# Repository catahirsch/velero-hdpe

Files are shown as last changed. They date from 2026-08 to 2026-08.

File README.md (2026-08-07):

# HDPE open daysailer

A 6.48 m open daysailer in high-density polyethylene, developed from two base
models: the **RS Aira 22** (dimensional envelope, 6-seat cockpit, rig concept) and
the **Flow 19** (retractable pivot keel plus water ballast, no-winch
2:1 purchase).

Requirements come from `notes.txt`.

---

## Headline results

| | |
|---|---|
| LOA / beam / draft | 6.48 m / 2.35 m / 0.22 m keel up, 1.29 m down |
| Displacement | 750 kg light, 1730 kg full load (6 crew + 500 L) |
| Ballast | 213 kg lead (28.4%) + 500 L water in the bench tanks |
| Sail area | 22.0 m² upwind, SA/D 15.5 full load |
| Structure | rotomoulded HDPE double skin, 5 mm skins / 50 mm gap, 9.5 kg/m² |
| Envelope compliance | **0 violations** |
| Cockpit self-drains | yes, +56 mm with 6 crew and 500 L aboard |
| Self-righting from 180° | **no — AVS 112°** light, ~105° tanks full. See below. |

### Three findings worth knowing up front

**1. HDPE costs essentially nothing in weight.** A rotomoulded double skin at
346 kg is within 12 kg of the GRP shell implied by the Aira's published figures.
The 46 kg of ballast lost against the Aira is bought by the **electric
auxiliary** (+58 kg), not the plastic. But single-skin HDPE is *not* viable —
deflection governs, requiring 23 mm and 710 kg of shell.

**2. The requirement envelope is the RS Aira's spec sheet.** LOA 6.50, DIS 750,
SQM 22.0 (14+8) are that boat's numbers, near-verbatim. Useful to know, because
they already encode GRP structure and no electric drive.

**3. True self-righting is a beam problem, not a ballast or open-cockpit
problem.** Sealing the cockpit entirely moves AVS by ~1°. Adding 800 kg of lead
gets to 149°, not 180°. What works is narrowing: 1.80 m beam and ~450 kg of
ballast self-rights, at ~990 kg displacement — which breaks the 6-abreast
cockpit and the 750 kg cap. **This requires a decision.**

The water ballast (`BAL <500` = 500 L) lives **inside the bench seats** (client
decision): one 250 kg tank filled to windward is worth about two crew on the
rail, and empty benches are the cockpit's sealed reserve buoyancy. The height
trade is real: at bench height, filling both tanks *costs* ~6° of AVS (under-sole
tanks would have gained ~4° via the RNLI righting-tank mechanism). Operating
rule: with a full crew sail tanks-empty; short-handed, fill the windward tank.

## Documents

| | |
|---|---|
| [`docs/01-requirements.md`](docs/01-requirements.md) | Conflict-resolved requirements, provenance of every figure, open items |
| [`docs/02-design-spec.md`](docs/02-design-spec.md) | Full design: hull form, HDPE structure, systems, build method, certification |
| [`docs/03-self-righting.md`](docs/03-self-righting.md) | Trade study and four costed options for the self-righting conflict |
| [`docs/04-build-spec.md`](docs/04-build-spec.md) | **Builder's package**: dimensions + tolerances, materials with grades, scantlings, hard points, foil/rig dimensions, water-ballast system, build sequence |
| [`docs/05-regulatory.md`](docs/05-regulatory.md) | **Argentina (PNA) + Chile (DIRECTEMAR)** path: approvals, registration, equipment by zone, the water-ballast friction point — from the primary ordinances |
| [`docs/06-compliance-notes.md`](docs/06-compliance-notes.md) | Line-by-line compliance matrix against the client's notes.txt — 30/33 met, the 3 that need a decision |
| [`docs/09-diseno-estilo.md`](docs/09-diseno-estilo.md) | Diseño: paletas de color para HDPE, terminaciones, detalles de confort, anti-ideas |
| [`docs/07-cost-analysis.md`](docs/07-cost-analysis.md) | Cost of building in Chile: welded one-off ~USD 64k mid vs rotomoulded series; parameterized model in `calc/costs.py` |
| [`autoadrizante/specs.md`](autoadrizante/specs.md) | **Self-righting variant (chosen resolution, 2026-08-07)**: same open 2.35 m boat + sealed mast + 60 L masthead float, *modelled in the GZ curves* — recovers unaided to 156°, turtle energy 2516 → 302 J. Full parallel of `out/`: specs, [changes vs baseline](autoadrizante/cambios.md), report, audit (22 checks), costs, 3DM + previews, STL, offsets, 8-sheet planos, water renders, physics GIF, presentation PDF — plus an **expanded options study** (section 4 of `presentacion.pdf`; raw run in `opciones.txt`): 8 righting options vs notes.txt, incl. an inflatable masthead bag that reaches literal 180° on the 2.35 m hull |

## Client viewer

**Live:** https://catahirsch.github.io/velero-hdpe/

Everything — specs, options data, blueprints, PDFs, interactive 3D model,
design/colour studies, downloads — in one browser page. To run it locally
instead:

```bash
python3 -m http.server 8000     # from the project folder (or double-click visor.command)
# then open http://localhost:8000
```

`index.html` loads the options comparison live from `autoadrizante/opciones.json`,
renders `specs.md`/`cambios.md`, embeds `planos.pdf` and `presentacion.pdf`, and
shows the hull STL (variant with rig + masthead float, and the narrow Option D
reference) in an orbitable three.js viewer. Regenerating the model outputs
updates the page — nothing on it is hand-copied.

## Competition (concurso/)

A design competition for UTN naval-engineering students built on this project:
teams submit a 14-parameter JSON, `python3 -m concurso.evaluar` turns it into a
real boat on the same physics chain (GZ curves, weight budget, envelope) and
scores it; `concurso/leaderboard.py` builds the ranking shown at
[/concurso/](https://catahirsch.github.io/velero-hdpe/concurso/). Rules in
`concurso/bases.md`, challenges in `concurso/desafios.md`. The reference
variant scores 79.9/100 — that's the boat to beat.

## Running it

```bash
python3 -m calc.report            # full calculation chain  (~10 s)
python3 -m calc.trade             # self-righting sweeps    (~4 min)
python3 -m calc.options           # costed resolution options (~5 min)
python3 -m geom.hull --both       # STL meshes + tables of offsets
python3 -m geom.export_3dm --both # Rhino .3dm visualization models
python3 -m calc.costs             # Chilean build cost model -> out/costs.txt
python3 -m geom.animate_righting  # self-righting animation -> out/selfrighting.gif
python3 -m calc.presentation      # client-facing PDF -> out/presentacion.pdf
python3 -m calc.audit             # buildability audit (15 physical checks)
python3 -m geom.drawings          # construction drawings -> out/planos.pdf
python3 -m geom.render_ideas      # design study: colorways + styling
python3 -m geom.render_scene      # 'photos': boat on the water, lit + reflections
```

Requires numpy, scipy, matplotlib; `rhino3dm` additionally for the .3dm export.
Polygon clipping and the STL writer are implemented directly.

### Outputs, in `out/`

| File | Contents |
|---|---|
| `report.txt` | Geometry, scantlings, weights, hydrostatics, stability, compliance |
| `trade_study.txt` | Ballast / beam / cockpit / depth sweeps and the frontier |
| `options.txt` | The four resolution options with costs |
| `gz_curves.png` | GZ curves, 0–180°, intact and flooded, light and loaded |
| `hull_lines.png` | Body plan, profile, plan |
| `trade_frontier.png` | Self-righting frontier and AVS vs ballast ratio |
| `hull_baseline.stl` | Baseline hull mesh, metres |
| `hull_selfrighting.stl` | 1.80 m beam variant that meets the requirement (452 kg keel) |
| `offsets_*.txt` | Tables of offsets for lofting or a builder |
| `boat_baseline.3dm` | Rhino model: hull with cockpit, keel, rudders, rig, tanks, waterlines — layered |
| `boat_selfrighting.3dm` | Same for the 1.80 m beam variant |
| `preview_3dm.png`, `preview_cockpit.png` | Quick renders of the .3dm contents |
| `foto_patagonia_navegando.png`, `foto_aira_fondeado.png` | El bote **en el agua**: renders iluminados con flotación y escora reales, velas izadas (`geom/render_scene.py`) |
| `diseno_colores.png`, `diseno_perfil.png` | Estudio de diseño: 4 paletas de color + elementos de estilo (`geom/render_ideas.py`) |
| `planos.pdf` | **7 láminas de construcción acotadas** (GA, formas, sección maestra, quilla, espejo/timón, plano vélico, lastre de agua) |
| `audit.txt` | Auditoría de constructibilidad — 15 verificaciones físicas, todas PASS |
| `presentacion.pdf` | **Resumen completo en castellano, listo para presentar** (12 páginas) |
| `selfrighting.gif` | **Animación**: ambos botes soltados invertidos — el base queda tortuga, la variante 1.80 m vuelve sola (`geom/animate_righting.py`) |

## Code layout

```
calc/
  params.py       all design parameters, provenance-tagged  <- start here
  geometry.py     stations, polygon clipping, heeled hydrostatics
  scantlings.py   HDPE panel sizing, creep-derated
  weights.py      weight and VCG budget; ballast as the remainder
  stability.py    GZ curves 0-180 deg, intact and flooded; sail carrying
  trade.py        parameter sweeps for the self-righting study
  options.py      costed resolution options
  report.py       driver -- runs everything, writes report and plots
geom/
  hull.py         mesh generation, STL export, developability check
  export_3dm.py   Rhino .3dm export: full boat on layers, for visualization
  animate_righting.py  physics animation of the self-righting comparison
calc/
  presentation.py the client-facing PDF builder (Spanish)
  audit.py        buildability audit: 15 physical consistency checks
geom/
  drawings.py     dimensioned construction drawings (7 sheets, Spanish)
```

Every parameter lives in `calc/params.py`, tagged with its source:
`[AIRA]` published spec, `[FLOW]` from `notes.txt`, `[NOTES]` stated in the brief,
`[ASSUM]` an assumption, `[MAT]` a material property. Change an assumption there
and the whole chain follows.

## Method notes

- **Stability** is computed from real geometry, not coefficients: each station is
  rotated into the earth frame and clipped against the waterplane with
  Sutherland-Hodgman, then integrated. Clipping a simple polygon against one
  half-plane leaves degenerate edges lying exactly along the clip line, where
  they contribute nothing to the shoelace area — so areas and centroids are exact
  without a geometry library.
- **Two GZ curves** are produced for every case. *Intact* treats the cockpit as
  watertight and is valid only up to the downflooding angle (44°). *Flooded* lets
  the cockpit fill once its opening immerses, and is the physically meaningful
  curve beyond that. The difference between them is small, which is itself the
  key result in the trade study.
- **Displacement is not held constant** in the trade sweeps. Ballast is added on
  top of the fixed weight, so each figure shows the displacement it implies.
- **ISO 12215-5 has no rotomoulded-PE path.** Pressures follow its form so the
  numbers are recognisable, but they are indicative, not a compliance route. At
  6.50 m the boat falls under ISO 12217-2, not 12217-3 — 0.50 m the wrong side of
  a cliff edge in certification cost.

## Caveats

- Flow 19 figures are unverified — its source URL returns HTTP 403.
- The flooded-cockpit model **removes buoyancy but does not add trapped water as
  weight**. That is correct for a cockpit draining aft through an open transom at
  moderate heel, where the internal water level equals the sea. At large heel and
  inverted, some water would be trapped above sea level, and its weight would
  reduce GZ further. So the model is **optimistic about self-righting** — and the
  boat still fails the test. The conclusion in `docs/03` is robust in the
  direction that matters.
- Aerodynamic heeling uses a single effective coefficient (1.05); it is sizing-
  grade, not VPP-grade.
- Panel formulas assume clamped long plates. Real corners and openings need
  detailed checks.
- No structural FEA. The hard points in `docs/02` §6 are where that effort
  belongs.

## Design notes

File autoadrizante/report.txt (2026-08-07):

==============================================================================
VARIANTE AUTO-ADRIZANTE -- masthead buoyancy, modelled honestly
==============================================================================
  Concept: baseline 2.35 m open daysailer, unchanged, plus a sealed
  spar (30 L usable) and a 60 L / 2.5 kg crown float.
  Design condition for the claim: keel DOWN and LOCKED, tanks EMPTY.

==============================================================================
1. WEIGHT BUDGET  (float aloft, paid for by the keel remainder)
==============================================================================
item                                     kg    z (m)      kg.m   note
------------------------------------------------------------------------------------------------------
HDPE shell (hull+deck)                346.3    0.420     145.4   9.5 kg/m2 x 32.5 m2
keel case + pivot structure            22.0    0.350       7.7   welded PE bosses, bolted
rudder + tiller (single, kick-up)      15.0    0.550       8.2   centreline transom-hung; client amendment 2026-08-06
mast + boom + standing rig             32.0    3.100      99.2   short mast, no backstay
sails (main + jib + furler)            16.0    2.200      35.2   square-top, lazy bag
deck hardware + 2:1 systems            19.0    0.780      14.8   no winches
electric motor                         26.0    0.550      14.3   ~4 kW outboard format
battery                                31.6    0.220       6.9   3.0 kWh LiFePO4
spray hood + cockpit tent              11.0    0.950      10.4   stowed
anchor, lines, safety gear             18.0    0.400       7.2   
keel ballast (lead)                   210.6   -0.860    -181.1   REMAINDER of the 750 kg cap, minus the crown float
masthead crown float                    2.5    9.550      23.9   60 L PE ellipsoid + bracket
------------------------------------------------------------------------------------------------------
LIGHT (incl. ballast)                 750.0    0.256
LOADED (6 crew + water)              1730.0    0.555

  VCG light rises 31 mm for the float -- the GZ curves below already carry that penalty.

==============================================================================
2. GZ CURVES  (2.35 m beam; 'con aparejo' counts the sealed rig)
==============================================================================
  case                     GZmax     AVS  rec.limit  neg area  GZ>0 to 180
  light/flooded/bare       0.643   109.8      109.8    0.3420        False
  light/flooded/rig        1.029   155.8      155.8    0.0411        False
  light/intact/rig         1.031   154.8      154.8    0.0490        False
  loaded/flooded/rig       0.373    83.6      124.0    0.1471        False

==============================================================================
3. VERDICT  (governing case: light ship, cockpit flooded, tanks empty)
==============================================================================
  Bare hull (baseline):   AVS 110 deg, stable inverted,
                          0.342 m.rad = 2516 J holding it turtle.
  With sealed rig+float:  GZ stays positive past 110 deg --
                          the boat recovers unaided from any heel up to 155.8 deg.
                          Residual inverted pocket: 155.8-180 deg, 0.0411 m.rad = 302 J
                          (8x shallower than the baseline's).
  Energy barrier guarding that pocket (area 110-156 deg): 0.358 m.rad = 2633 J --
  to turtle, a seaway must push the boat through ALL of it; to release,
  it only has to nudge the boat 24.2 deg. In any water rough
  enough to capsize this boat, the pocket is not a resting state.

  Claim for the spec sheet / placard: AUTO-ADRIZANTE con quilla abajo y
  trabada y tanques vacios; el flotador de tope hace el 180 inalcanzable
  y el barco vuelve solo desde cualquier escora hasta 156 grados.

==============================================================================
4. FLOAT SIZING  (why 60 L: sweep at 31 stations, 5 deg)
==============================================================================
   float (L)  rec.limit  neg area  GZ>0 to 180
           0      123.4    0.2211        False
          20      137.6    0.1279        False
          40      148.1    0.0726        False
          60      155.9    0.0396        False
          80      162.0    0.0208        False
  Below ~40 L the float cannot carry the immersed rig's weight with
  margin (rig 32 kg + float, buoyancy needed > ~35 kg); 60 L gives a
  1.7x margin and costs 2.5 kg. Beyond 80 L the recovery limit barely
  moves -- the residual pocket is pinched against 180 by symmetry, not
  by float size.

==============================================================================
5. OTHER CONDITIONS
==============================================================================
  Loaded (6 crew + 500 L), flooded, with rig: recovery limit 124 deg.
  Keel UP: NOT self-righting in any variant -- keel-up is a launch/
  recovery state only. The keel lock (L4) is what makes the claim hold
  through a knockdown: an unlocked keel falling into the case at 120 deg
  would remove most of the righting moment when it is needed most.
  Downflooding angle at full load: 37 deg (unchanged from base).

Report written to /Users/catalinahirsch/Desktop/bote/autoadrizante/report.txt

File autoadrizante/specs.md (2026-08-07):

# Especificacion — variante auto-adrizante

Velero abierto HDPE 6.48 m, identico al baseline en casco, cockpit, quilla,
aparejo y sistemas, mas el **paquete de flotabilidad de tope de mastil**. La
decision que encierra esta variante: mantener el daysailer abierto y liviano,
y comprar los grados de adrizado que faltan con **volumen sellado en altura**,
no con plomo.

## Dimensiones y pesos

| | |
|---|---|
| LOA / LWL | 6.48 m / 6.30 m |
| Manga | 2.35 m (se mantiene el cockpit de 6 plazas) |
| Calado | 0.30 m quilla arriba — 1.29 m abajo |
| Desplazamiento rosca | 750 kg (tope 750) |
| Quilla (plomo) | 211 kg (28.1 %) |
| Lastre de agua | 2 × 244 L en bancos-tanque — **vacios para la condicion de diseno** |
| Superficie velica | 22.0 m² (mayor 14 + foque 8) |
| Estructura | HDPE doble piel 2×5 mm / 50 mm, 9.5 kg/m² |

## El paquete auto-adrizante (lo unico que cambia)

| Elemento | Especificacion |
|---|---|
| Flotador de tope | 60 L, elipsoide PE rotomoldeado 1.00 × 0.34 m, carenado proa-popa, 2.5 kg con soporte |
| Mastil sellado | 30 L utiles: espuma de cierre en pie, tope y cajeras; drizas externas o en conducto |
| Traba de quilla | obligatoria en posicion BAJA (ya en L4): una orzada no debe retraerla |
| Costo en plomo | el flotador se paga con 2.5 kg de quilla (213 → 211 kg) |

## Resultado de estabilidad (condicion gobernante: rosca, cockpit inundado, tanques vacios)

| | Sin flotador (base) | Con mastil sellado + flotador |
|---|---|---|
| AVS | 110° | GZ sigue positivo mas alla de 110° |
| Limite de recuperacion sin ayuda | 110° | **155.8°** |
| Energia que sostiene la tortuga | 2516 J | 302 J |
| Equilibrio invertido estable | si — el barco queda tortuga | reducido a un bolsillo de 24.2° junto a 180° |

**La afirmacion honesta**: con quilla abajo y trabada y tanques vacios, el
barco vuelve solo desde cualquier escora hasta 156°. El bolsillo
invertido residual (24.2° de ancho, 302 J) no es un
estado de reposo en ninguna mar capaz de dar vuelta el barco: para entrar hay
que atravesar toda la barrera positiva de la curva; para salir alcanza con
24° de perturbacion. A efectos operativos: **anti-tortuga +
retorno autonomo**, y las cinchas de piso quedan como respaldo (y para la
condicion quilla-arriba en playa).

## Condicion de diseno — placa junto a la quilla (grabar)

> AUTO-ADRIZANTE SOLO CON: QUILLA ABAJA Y TRABADA · TANQUES VACIOS
> QUILLA ARRIBA = SOLO BOTADURA / PLAYA · LLENAR TANQUES = VER PLACA DE LASTRE

El lastre de agua queda como sistema de rendimiento (tanque de barlovento con
poca tripulacion), nunca como dependencia de seguridad: la curva verde se
calcula con tanques vacios.

## Lo que esta variante NO cambia

Cockpit 3.20 × 1.72 m de 6 plazas, piso autoachicable (+56 mm a plena carga),
espejo semiabierto, bancos-tanque sellados, cuddy con doble tambucho, aparejo
sin winches 2:1, timon unico abatible, motor electrico con bateria bajo el
piso, remolque sin permiso especial. Desplazamiento rosca sigue en
750 kg.

## Archivos de esta carpeta

| Archivo | Contenido |
|---|---|
| `specs.md` / `cambios.md` | esta especificacion + registro de cambios vs baseline |
| `report.txt` | corrida completa del modelo (pesos, curvas, dimensionado del flotador) |
| `audit.txt` / `costs.txt` | auditoria 22 verificaciones (15 base + 7 del flotador); costos con delta |
| `gz_curves.png` / `hull_lines.png` | curvas GZ con y sin paquete de tope; plano de lineas |
| `boat_autoadrizante.3dm` | modelo Rhino por capas, con flotador de tope |
| `preview_3dm.png` / `preview_cockpit.png` | vistas rapidas del 3DM |
| `hull_autoadrizante.stl` | malla del casco (identica al baseline, m) |
| `offsets_autoadrizante.txt` | tabla de puntos para loftear |
| `planos.pdf` | 8 laminas: las 7 constructivas + L8 flotador y condicion de diseno |
| `selfrighting.gif` + `anim_*.png` | animacion fisica: soltados a 150°, con y sin paquete de tope |
| `foto_*.png` / `diseno_*.png` | el bote en el agua y estudio de color, flotador a la vista |
| `opciones.txt` / `.json` / `opciones_gz.png` / `opciones_board.png` | exploracion ampliada: 8 opciones de auto-adrizado contra notes.txt (insumos de la seccion 4 de la presentacion) |
| `presentacion.pdf` | resumen para el cliente en castellano, con la comparacion de opciones y recomendacion integradas |

Generado por `python3 -m calc.autoadrizante`, `geom.autoadrizante`,
`geom.render_autoadrizante`, `geom.animate_autoadrizante`,
`calc.audit_autoadrizante` y `calc.presentacion_autoadrizante`. Mismas
advertencias que el modelo base: el caso inundado no agrega el peso del agua
atrapada (optimista; cuantificado en docs/03), y el proyecto requiere firma
de ingeniero naval.

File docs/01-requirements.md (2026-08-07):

# Requirements — HDPE open daysailer

Derived from `notes.txt`, with every figure traced to a source. Nothing in this
document is invented; where a number had to be assumed it says so.

---

## 1. Where the envelope came from

The six dimensional limits in `notes.txt` are, to within rounding, the published
spec sheet of the **RS Aira 22**. That is worth stating plainly, because it means
the envelope is not an independent set of targets — it is one existing GRP boat's
achieved numbers, and it already encodes GRP's structural efficiency and the
absence of an electric drive.

| Note | Stated limit | RS Aira 22 (published) | Reading |
|---|---|---|---|
| `LOA <6.50` | 6.50 m | **6.50 m** | identical |
| `BEA <2.50` | 2.50 m | 2.20 m | rounded up to the EU road limit |
| `DIS <750` | 750 kg | **750 kg** | identical |
| `SQM <22` | 22 m² | **22.0 m²** (14.0 main + 8.0 jib) | identical |
| `BAL <500` | 500 **litres** of water ballast | — (Aira carries none) | see §2 |
| `CBD <1.30` | 1.30 m | 1.20 m | keel lowered |

Source: rssailing.com/project/rs-aira/, fetched 2026-08-06.

**Note on naming:** `notes.txt` line 17 reads *Aira 22* (RS Aira). The original
request said "Aria 22". The RS Aira is the boat.

The **Flow 19** figures on lines 26–33 could not be verified — the
carbonmade.com URL returns HTTP 403. They are used as recorded by the designer:
beam 2.30 m, draft 1.30 m, displacement 450 kg, 70 kg swing keel, 2 × 60 kg water
ballast, twin pivoting rudders, 2:1 purchase, no traveller, no backstay.

## 2. Resolved parameters

`CBD` (line 8) and `CND` (line 27) are the same parameter under two spellings.
Read as **keel depth, lowered** — not overall draft, which for a pivot-keel boat
is a different and much smaller number (canoe-body draft, computed at 0.22 m
light / 0.29 m loaded).

`DIS <750` is confirmed as **light/dry displacement including ballast**. Six crew
and the water ballast sit on top of it, so full-load displacement is ~1730 kg.
This is the definition the whole weight budget is built on.

`BAL <500` is confirmed (designer, 2026-08-06) as **500 litres of water
ballast** — not a cap on lead. The design carries 2 × 250 kg tanks (488 L of
seawater, inside the cap) built into the cockpit benches and double sole, so the
tanks are the sealed reserve buoyancy when empty and the ballast when full. The
keel ballast is a separate quantity, solved as the remainder of the 750 kg
budget (213 kg).

## 3. Intended use — settled

An open daysailer, not a cruiser:

- 6-seat cockpit, no cabin; bow cuddy with a fabric shelf (`estante tela`)
- Self-draining cockpit, draining aft through a semi-open transom
- Spray hood plus cockpit tent for shelter; flat foredeck for sunbathing
- Electric auxiliary
- Single centreline kick-up rudder with short tiller (client amendment 2026-08-06; notes line 39 said two)
- Pivoting keel
- Furling jib, centred high boom, short mast, square-top main
- No traveller, no backstay, no winches — 2:1 purchase throughout
- Double bow hatch (`doble tambucho proa`); removable righting straps on the
  sole; 1″×1″ foot-bracing battens

## 4. What each base model contributes

**RS Aira 22** — the dimensional envelope, the 6-adult cockpit, the general
rig concept (high centred boom, short mast, square-top main, furling headsail),
and the reference point for what 750 kg buys in a 6.5 m hull.

**Flow 19** — the ballast strategy (light pivoting keel plus symmetric water
ballast), the no-winch 2:1 purchase system (its twin rudders were later dropped by client amendment), and the
no-traveller/no-backstay rig simplification.

## 5. Requirements that conflict

### 5.1 True self-righting vs. everything else — **unresolved, decision needed**

The stated requirement (confirmed after the conflict was flagged) is recovery
from 180° unaided. The calculations say this is **not achievable within the rest
of the brief**, and the reason is not the one usually assumed.

- The baseline reaches AVS **112°** with 213 kg of ballast (28% ratio) and has a
  **stable inverted equilibrium**.
- Ballast alone does not fix it. Even at 1000 kg of lead — displacement ~1540 kg
  on a 6.5 m hull — AVS only reaches 149°.
- **Sealing the cockpit barely helps** (AVS 112.4° sealed vs 112.2° flooded).
  When inverted the boat floats so high that the cockpit is mostly out of the
  water anyway. The "open boat loses its reserve buoyancy" argument is wrong here.
- The binding constraint is **beam-to-depth ratio**. 2.35 m of beam on 0.755 m of
  depth is a hull that is stable upside down, and that is the same form stability
  that makes it stiff upright and lets it carry 6 people and 22 m².

Cheapest configuration that genuinely self-rights: **1.75–1.80 m beam, 417–452 kg
ballast, ~954–988 kg displacement** — which breaks the 6-abreast cockpit and
exceeds `DIS 750` by 27–32%.

Full trade study and four costed options: [`03-self-righting.md`](03-self-righting.md).

### 5.2 Lead is scarce; water is not

The 750 kg budget leaves **213 kg** for the keel after structure, rig, foils,
hardware and the electric drive — 46 kg less than the Aira, bought by the
electric auxiliary. The 500 L of water ballast rides on top of the light-ship
budget and lives **inside the bench seats** (client decision): filled to
windward it is worth about two crew on the rail; empty, the benches are the
cockpit's reserve buoyancy. Filling both tanks symmetrically costs ~6° of AVS
at bench height and is only worth doing for motion damping in a seaway with a
small crew.

### 5.3 ISO certification vs. the material — cost and schedule risk

**ISO 12215-5 has no rotomoulded-PE path.** Its scantling formulas cover FRP,
aluminium, steel, plywood and wood. Certification of a PE hull runs through
physical testing instead.

At 6.50 m hull length the boat falls under **ISO 12217-2** (sailing boats,
hull length ≥ 6 m) — *not* 12217-3, which covers boats under 6 m. This is a
cliff edge, not a gradient: dropping hull length below 6.00 m would move the boat
into a materially simpler and cheaper stability-assessment path. At 6.50 m LOA
the boat sits just the wrong side of it, by 0.50 m.

## 6. Questions the notes left open

| # | Question | Status |
|---|---|---|
| 1 | Freeboard and cockpit sole height (line 30) | **Resolved by calculation.** Sole at 0.385 m above baseline drains with +168 mm margin light, **+56 mm** with 6 crew and 500 L of water ballast aboard (1730 kg). Tight but positive; raising the sole 30 mm would buy comfort at the cost of cockpit depth. |
| 2 | How to fill water ballast under way (line 57) | **Open.** Scoop/venturi intake vs. powered pump changes electrical load and thru-hull count. Emptying by air pump is already specified (line 56). |
| 3 | True self-righting | **Open — needs a decision.** See §5.1. |
| 4 | Flow 19 source data | **Blocked.** URL returns 403. |

## 7. Assumptions this model makes

All are tagged `[ASSUM]` in `calc/params.py` and can be changed in one place:

- Beam 2.35 m (between the Aira's 2.20 and the 2.50 road cap, for form stability)
- LOA 6.48 m, LWL 6.30 m
- Canoe-body depth 0.755 m; cockpit 3.20 m × 1.72 m; sole at 0.385 m
- Keel ballast VCG 0.86 m below baseline, lowered
- Water ballast tanks: 2 × 250 kg, centroid 0.26 m above baseline, 0.72 m off
  centreline, built into the benches and double sole
- Electric drive: ~4 kW outboard-format motor (26 kg) + 3.0 kWh LiFePO₄ (32 kg)
- Crew 80 kg each (ISO uses 75 kg; 80 is more honest)
- Design category C (inshore)
- HDPE: ρ 950 kg/m³, short-term flexural modulus 1100 MPa, **creep-derated
  design modulus 250 MPa**, allowable bending stress 7 MPa

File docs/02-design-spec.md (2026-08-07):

# Design specification — HDPE open daysailer

6.48 m open daysailer in high-density polyethylene, based on the RS Aira 22
(envelope, cockpit, rig concept) and the Flow 19 (ballast strategy,
purchase system).

All figures from `calc/report.py`; raw output in `out/report.txt`.

---

## 1. Principal dimensions

| | Baseline | Limit | RS Aira 22 |
|---|---|---|---|
| LOA | 6.48 m | 6.50 | 6.50 m |
| LWL | 6.30 m | — | 6.45 m |
| Beam (sheer) | 2.35 m | 2.50 | 2.20 m |
| Beam (chine) | 1.88 m | — | — |
| Canoe-body depth | 0.755 m | — | — |
| Draft, keel up | 0.22 m light / 0.29 m loaded | — | — |
| Draft, keel down | 1.29 m | 1.30 | 1.20 m |
| Displacement, light | 750 kg | 750 | 750 kg |
| Displacement, full load (6 crew + 500 L) | 1730 kg | — | — |
| Keel ballast | 213 kg (28.4%) | — | 250 kg (33.3%) |
| Water ballast | 2 × 250 kg (488 L) | 500 L | none |
| Sail area, upwind | 22.0 m² | 22.0 | 22.0 m² |
| SA/D (full load) | 15.5 | — | — |
| VCG, light | 0.239 m above baseline | — | — |
| Design category | C (inshore) | — | — |

Baseline z = 0 is the lowest point of the canoe body. x = 0 at the transom.

## 2. Hull form

**Hard chine, two panels per side.** This is not stylistic. Both viable HDPE
processes want it: rotomoulding needs a shape that releases from a shell tool
without undercuts, and welded-sheet construction needs panels that develop flat.
A hard chine also gives more form stability than a round bilge of the same beam,
which matters when the ballast ratio is only 27%.

Plan form carries beam well aft to support the 6-seat cockpit and the semi-open
transom, with a fine entry forward to stop it pounding. Moderate rocker, flat run
aft.

### Developability

From `geom/hull.py`, using the standard test `det[t₁, t₂, (P₂−P₁)] = 0`:

| Panel | Mean twist | Peak | Location of peak |
|---|---|---|---|
| Bottom | 0.039 | 0.199 | x = 5.94 m |
| Side | 0.018 | 0.161 | x = 5.94 m |

**Sheet-formable from the transom to x = 4.10 m — 63% of LOA.** Forward of that
the entry twists too hard for flat PE sheet. Three ways out:

1. Rotomould the stem as a separate piece and butt-weld it on
2. Split the forward panels into narrower strakes
3. Straighten the entry (costs seakeeping)

If the whole hull is rotomoulded in one shot this is moot — a shell tool does not
care about developability.

## 3. Structure — the part that decides whether HDPE works

### Material design values

| Property | Value | Note |
|---|---|---|
| Density | 950 kg/m³ | rotomoulding grade |
| Flexural modulus, short-term | 1100 MPa | **not a design value** |
| Flexural modulus, creep-derated | **250 MPa** | 10 yr, 20 °C — use this |
| Allowable bending stress | 7.0 MPa | long-term |
| Weldable | yes | |
| Adhesively bondable | **no** | non-polar surface; weld or bolt |
| Thermal expansion | ~200 × 10⁻⁶ /K | ~10× steel — detail for it |

Designing to the short-term modulus is the single most common way plastic boat
structures end up floppy. Everything below uses 250 MPa.

### Deflection governs, not stress

For HDPE at this size the stiffness requirement is always the binding one:

| Panel | Pressure | Span | t for strength | t for stiffness | Governs |
|---|---|---|---|---|---|
| Bottom | 27.1 kPa | 0.40 m | 17.6 mm | **23.0 mm** | deflection |
| Side | 21.4 kPa | 0.40 m | 15.6 mm | **21.2 mm** | deflection |
| Deck | 7.5 kPa | 0.46 m | 10.6 mm | **17.2 mm** | deflection |
| Cockpit sole | 7.5 kPa | 0.36 m | 8.3 mm | **13.5 mm** | deflection |

Pressures follow the *form* of ISO 12215-5 (category C, m_LDC 1230 kg) so they are
recognisable, but see §6 — that standard does not actually cover PE.

**Single skin is not viable.** 23 mm of solid HDPE over 32.6 m² of shell is
**710 kg** — the whole displacement budget, before rig, keel or crew. The
HDPE/GRP thickness ratio for equal panel stiffness is 2.96×.

### Double skin is the answer

Two skins separated by a gap act as the flanges of an I-beam. Equivalent solid
thickness is `(6·t·d²)^(1/3)`, typically 4–5× the material actually used.

**Specification: 5.0 mm skins, 50 mm gap, kiss-offs at 75 mm pitch.**

| Panel | t equivalent | Required | Face stress | Skin needed locally | Verdict |
|---|---|---|---|---|---|
| Bottom | 42.2 mm | 23.0 mm | 1.44 MPa | 4.3 mm | **pass** |
| Side | 42.2 mm | 21.2 mm | 1.14 MPa | 4.0 mm | **pass** |
| Deck | 42.2 mm | 17.2 mm | 0.53 MPa | 2.8 mm | **pass** |
| Cockpit sole | 42.2 mm | 13.5 mm | 0.32 MPa | 2.8 mm | **pass** |

Areal mass **9.5 kg/m²** — 44% of the single-skin mass. Face stresses are an
order of magnitude below allowable; the kiss-off pitch is what sizes the skins,
not the global bending.

Shell mass: 32.6 m² × 9.5 kg/m² × 1.12 (reinforcement) = **346 kg**.

### The material is weight-neutral — the electric drive is not

Backing the Aira's shell mass out of its published figures (750 kg total, 250 kg
ballast, minus the same non-shell items this design carries, minus the electric
drive it does not have) gives an implied GRP shell of **358 kg**.

| | kg |
|---|---|
| RS Aira shell, implied (GRP) | 358 |
| This shell, HDPE double-skin | 346 |
| **Material penalty** | **−12** |
| Electric motor + battery | **+58** |
| **Ballast: Aira 250 → this boat 213** | **−37** |

**HDPE costs essentially nothing in weight.** A rotomoulded double skin is as
efficient as a stiffened glass laminate. The 46 kg of ballast lost against the
Aira is bought by the electric auxiliary, not the plastic.

If ballast ratio matters more than motoring range, a 1.5 kWh pack instead of
3.0 kWh returns ~16 kg to the keel.

## 4. Weight budget

Ballast is not an input — it is the remainder under the 750 kg cap.

| Item | kg | z (m) | Note |
|---|---|---|---|
| HDPE shell (hull + deck) | 346.3 | 0.420 | 9.5 kg/m² × 32.5 m² |
| Keel case + pivot structure | 22.0 | 0.350 | welded PE bosses, bolted |
| Rudder + tiller (single, kick-up) | 15.0 | 0.550 | client amendment 2026-08-06 |
| Mast + boom + standing rig | 32.0 | 3.100 | short mast, no backstay |
| Sails (main + jib + furler) | 16.0 | 2.200 | square-top, lazy bag |
| Deck hardware + 2:1 systems | 19.0 | 0.780 | no winches |
| Electric motor | 26.0 | 0.550 | ~4 kW outboard format |
| Battery | 31.6 | 0.220 | 3.0 kWh LiFePO₄ |
| Spray hood + cockpit tent | 11.0 | 0.950 | stowed |
| Anchor, lines, safety gear | 18.0 | 0.400 | |
| **Keel ballast (lead)** | **213.1** | **−0.860** | **remainder** |
| **Light, incl. ballast** | **750.0** | **0.239** | |
| **Full load (6 crew + 500 kg water)** | **1730.0** | **0.402** | |

## 5. Systems and layout

### Cockpit and freeboard — the open question, resolved

Cockpit 3.20 m × 1.72 m, sole at 0.385 m above baseline.

| Condition | Waterline | Sole freeboard | Drains? |
|---|---|---|---|
| Light ship | 0.217 m | **+168 mm** | yes |
| 6 crew + 500 kg water ballast (1730 kg) | 0.329 m | **+56 mm** | yes |

The self-draining cockpit works, draining aft through the semi-open transom, with
56 mm of margin in the worst case — tight but positive. If more margin is wanted,
each 10 mm of sole height buys 10 mm of margin at the cost of cockpit depth;
alternatively sail with one tank when fully crewed. Sheer freeboard 0.538 m light.

This closes `notes.txt` line 30.

### Ballast

- **Retractable pivoting keel, 213 kg total (163 lead + 50 fin)**, 1.29 m draft lowered, 0.30 m raised, pivot at
  x = 3.30 m. Ballast VCG 0.86 m below baseline when down.
- **Water ballast, 2 × 250 kg (488 L total, inside the 500 L cap)**, tanks built
  **into the cockpit bench seats**: sealed HDPE boxes, sole (0.385) to seat top
  (0.80), inboard face at y = 0.44, outboard face at the cockpit wall
  (y = 0.86). Water centroid when full: z ≈ 0.48, y ≈ ±0.65.

The bench-tanks do triple duty, and the three roles should be kept distinct:

1. **Empty and sealed** — they *are* the reserve buoyancy of the benches
   (`reserva flotabilidad`, line 38) and the seats. No separate foam or tankage.
2. **One tank filled to windward** — 250 kg at 0.65 m of lever ≈ 1.6 kN·m,
   about **two crew on the rail**. This is the payoff that earns the plumbing:
   sailing stiffness when short-handed. Heel at 16 kt drops from 10° to 5°.
3. **Both tanks filled** — adds 500 kg for damping and inertia only. At bench
   height this **costs ~6° of AVS** (111° → 105° light ship), unlike under-sole
   tanks which would gain ~4°. That is the price of seats-as-tanks; it was a
   deliberate trade for build simplicity, seating and reserve buoyancy.

**Operating rule that falls out of the numbers:** water ballast substitutes for
crew weight, it does not stack with it. With 5–6 crew aboard, sail tanks-empty
(the crew *is* the ballast; full tanks put the loaded AVS at ~85°). With 1–3
crew, fill the windward tank. Symmetric fill is for motoring or running in a
seaway, short-handed.

Only the keel does real work at large heel in every condition.

**Filling under way remains open** (`notes.txt` line 57). Scoop/venturi intake is
passive and free but only works above ~3 kt and adds two thru-hulls; a powered
pump adds ~180 W and a load on the same battery as the motor. Recommend the
scoop, with the air pump already specified for emptying (line 56).

### Rig

Centred high boom (1.80 m above baseline — audited to clear seated heads), short mast (8.60 m), square-top main 14.0 m²,
furling jib 8.0 m², no traveller, no backstay, no winches, 2:1 purchase.

Sail-carrying, 6 crew aboard:

| True wind | Tanks symmetric | Windward tank only |
|---|---|---|
| 8 kt | 2° | 0° |
| 12 kt | 5° | 1° |
| 16 kt | 10° | 5° |
| 20 kt | 17° | 12° |
| 25 kt | 28° | 25° |

Peak righting moment at **28 kt steady** — gusts reach it sooner, so first reef
goes in around 18 kt. SA/D 15.5 at full load (18.3 without the water ballast) is
moderate; the boat is stiff for its sail area.

Downflooding angle is **37°** at full load. For an open boat that is the number
to design the crew drill around.

### Foils and steering

Single centreline kick-up rudder with a short tiller (client amendment
2026-08-06 — the notes and Flow 19 had two). Kick-up keeps beaching and trailer
recovery. The lone blade is drawn deeper (0.85 m immersed) than each of the
former twins so it keeps grip at the 20–30° heel this boat sails at; expect
some rudder emergence in the worst gusts — ease the main first.

### Propulsion

~4 kW outboard-format electric, 3.0 kWh LiFePO₄ mounted low (z = 0.22 m) under
the sole. At 4 kt cruise the pack gives roughly 1.5–2 h of motoring.

## 6. Build method and certification

### Which process

| | Rotomoulding | Welded sheet |
|---|---|---|
| Tooling | High — shell tool for a 6.5 m hull | Low |
| Double skin | Natural, with kiss-offs | Must be fabricated |
| Developability | Irrelevant | Only 63% of LOA works as-drawn |
| Unit cost at volume | Low | Flat |
| Viable at 1–5 boats | No | Yes |

**Rotomoulding for production, welded sheet for a prototype.** The scantlings
above assume the rotomoulded double skin; a welded prototype needs an equivalent
stiffened structure — 12 mm sheet on 200 mm-pitch welded top-hat stiffeners gets
close at a weight penalty of roughly 40 kg.

### Hard points — the main structural risk

HDPE **cannot be adhesively bonded**. Every load path is welded or mechanically
fastened, and PE creeps under sustained load, so bolts pull through over time
unless the load is spread.

The rig makes this worse than usual: no traveller and a centred boom put the
entire mainsheet load into one centreline point, and with no backstay the
forestay is reacted by shroud geometry alone.

| Hard point | Detail |
|---|---|
| Mast step | Welded PE box, through-bolted to an aluminium spine spanning ≥3 station frames. Do not rely on the shell. |
| Chainplates | Full-depth aluminium backing plates through both skins, load spread over ≥0.15 m². |
| Mainsheet anchor | Centreline welded PE boss, through-bolted to a transverse alloy beam bearing on the keel case. |
| Keel pivot | Machined alloy trunnion in a welded PE case, bolted to a full-height bulkhead. Highest cyclic load on the boat. |
| Rudder gudgeons | Bolted through alloy backing plates, not tapped into PE. |
| Thermal | ~200 × 10⁻⁶ /K expansion: every alloy-to-PE joint needs slotted holes or compliant bushes, or it will yield through a season. |

### Certification path

**ISO 12215-5 has no rotomoulded-PE path** — it covers FRP, aluminium, steel,
plywood and wood. The scantling numbers in §3 are indicative, not a compliance
route. CE certification of a PE hull runs through **physical testing**:
instrumented panel tests to demonstrate equivalence, plus ISO 12217-2 stability
trials.

At 6.50 m hull length the boat falls under **ISO 12217-2** (sailing boats,
hull length ≥ 6 m). Below 6.00 m it would fall under 12217-3, which is a
materially cheaper and simpler path. **The boat is 0.50 m the wrong side of that
line.** If certification cost is a driver, shortening to under 6.00 m hull length
is the single highest-leverage change available — and it is worth pricing before
committing to 6.48 m.

Treat certification as a cost and schedule item with real risk attached, not a
checkbox. Budget for a test programme.

## 7. Open items

1. **Self-righting** — requirement conflicts with the brief. Decision needed.
   See [`03-self-righting.md`](03-self-righting.md).
2. **Water ballast filling under way** — scoop vs pump. Recommend scoop.
3. **Flow 19 source data** — unverified, URL returns 403.
4. **Certification strategy** — test programme scope and cost; whether to drop
   below 6.00 m hull length.

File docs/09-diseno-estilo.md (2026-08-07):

# Diseño y estilo — colores, terminaciones y detalles

Renders en `out/diseno_colores.png` (4 paletas), `out/diseno_perfil.png`
(elementos de estilo numerados) y **escenas en el agua** en
`out/foto_patagonia_navegando.png` / `out/foto_aira_fondeado.png` — el modelo
real flotando en su línea de flotación de cálculo, con velas y escora
(`python3 -m geom.render_scene`). Regenerables con `python3 -m geom.render_ideas`.

La restricción que ordena todo: **en HDPE el color va en la resina** (masterbatch
al momento de moldear). No hay pintura ni gelcoat — nada adhiere al PE — así que
el esquema de color es una decisión *previa al molde*, y a cambio el color es
pasante: los rayones y el uso no se notan como en gelcoat.

---

## 1. Las tres reglas técnicas del color en PE

1. **Cubierta, bancos y piso siempre claros.** El PE oscuro al sol toma 20–30 °C
   más que el claro; en un material que fluye con la temperatura eso significa
   más dilatación, más creep en herrajes, y quemarse al sentarse. Los costados
   pueden ser oscuros (verticales, menos insolación).
2. **El negro/carbono es el PE más longevo al UV** — por eso los kayaks de
   expedición son oscuros. Un casco grafito con cubierta clara es la combinación
   más durable.
3. **Blanco/claro es el más estable dimensionalmente** — si la prioridad es
   minimizar movimiento térmico (tolerancias de herrajes), la base clara gana.

## 2. Cuatro paletas propuestas (render en `diseno_colores.png`)

| Paleta | Costados | Franja | Cubierta | Bancos | Carácter |
|---|---|---|---|---|---|
| **PATAGONIA** | grafito | naranja | gris claro | naranja | máxima vida UV, no muestra el uso, acentos de alta visibilidad SAR |
| **CHILOÉ** | petróleo | crema | crema | pads "teca" | clásico de canal, esconde algas en la franja |
| **AIRA** | blanco roto | azul | gris perla | azul | el más fresco al sol, look astillero |
| **ARENA** | arena | oliva | crema | oliva | discreto en fondeaderos australes |

Recomendación: **PATAGONIA** para uso intensivo/alquiler (durabilidad + no
muestra uso), **AIRA** para clima cálido o si mandan las tolerancias.

## 3. Elementos de estilo (perfil numerado en `diseno_perfil.png`)

1. **Defensa perimetral de PE soldada** en la borda — perfil D extruido, soldado
   sobre el cordón casco-cubierta: lo protege, remata la línea y es el "trim"
   natural del material.
2. **Nombre en bajorrelieve ruteado + inlay de soldadura** en color de contraste
   — el rótulo que no se despega nunca. (El vinilo sobre PE requiere flameado y
   dura poco; evitarlo.)
3. **Franja de flotación en color de acento** — esconde la zona que se ensucia
   y estiliza el perfil bajo.
4. **Matrícula grabada** en amuras + nombre en aletas + puerto en espejo — la
   exigencia CL/AR (A-41/014 II.E) resuelta con el mismo grabado del punto 2.
5. **Apéndices en gris oscuro** (quilla, timón galvanizado pintado no — el acero
   va galvanizado y puede llevar recubrimiento epoxi sobre el galvanizado).
6. **Antideslizante moldeado** — textura guijarro/diamante EN el molde para
   cubierta, tapas de banco y piso. Sin pinturas antideslizantes (no adhieren).

## 4. Confort y detalles de cockpit

- **Pads EVA tipo teca en las tapas de banco** (el look madera de la paleta
  CHILOÉ): se fijan con pernos de PE soldados por debajo o botones a presión
  pasantes — nunca adhesivo. Aíslan térmicamente el asiento (resuelve el PE
  caliente/frío) y son el "cushion" que no se vuela.
- **Respaldo bajo continuo**: la brazola de la cubierta lateral, redondeada en
  el molde a r ≥ 40 mm.
- **Estiba**: el volumen de banco sobre el nivel de llenado (0.57→0.80 m) queda
  utilizable como estiba seca por las tapas registro — bolsos estancos.
- **Cuddy**: estante de tela (notes línea 20) + bolsillos de red en las paredes;
  los dos tambuchos dan luz y ventilación.
- **Bañera nocturna**: la carpa sobre la botavara a 1.80 m da altura de asiento
  en todo el cockpit — 3.2 m de "camarote" de lona.
- **Piso**: listón 1"×1" soldado (notes línea 47) en el eje + textura moldeada.

## 5. Lo que NO hacer en PE (anti-ideas)

- Pintar o gelcoatear cualquier superficie — se despega, siempre.
- Vinilos grandes — flameado + vida corta; solo aceptable para numerales de
  regata temporales.
- Herrajes "decorativos" atornillados al PE sin placa — fluencia y pérdida.
- Teca real atornillada — dilatación diferencial 10× la arranca; EVA o PE
  texturado.
- Colores oscuros en superficies horizontales — regla 1.

## 6. Cómo se pide esto en producción

Rotomoldeo: el masterbatch define **un** color por pieza moldeada. El esquema
multicolor se logra por: (a) casco y cubierta moldeados por separado en colores
distintos (ya son dos piezas), (b) franja y defensa como perfiles PE soldados en
color de acento, (c) tapas de banco moldeadas aparte (color 3), (d) inlays de
soldadura para gráfica. En chapa (prototipo): cada plancha PE500 viene de color
de fábrica — el esquema se arma por despiece, con la misma lógica.

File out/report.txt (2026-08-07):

==============================================================================
1. HULL GEOMETRY
==============================================================================
  LOA                     6.480 m
  LWL                     6.300 m
  Max beam (sheer)        2.350 m
  Beam at chine           1.880 m
  Depth of canoe body     0.755 m
  Hull shell area         17.41 m2
  Deck + cockpit area     15.14 m2
  Total shell area        32.55 m2
  Cockpit                 3.20 m long x 1.72 m wide, sole at z=0.385 m

==============================================================================
2. HDPE SCANTLINGS
==============================================================================
  Design category C, m_LDC assumed 1230 kg
  Material: HDPE (rotomoulding grade)
    short-term flex modulus  1100 MPa
    creep-derated modulus    250 MPa  <- design value
    allowable bending stress 7.0 MPa

  panel             p (kPa)   span   t_str  t_defl     governs
  bottom               27.1   0.40    17.6    23.0  deflection
  side                 21.4   0.40    15.6    21.2  deflection
  deck                  7.5   0.46    10.6    17.2  deflection
  cockpit_sole          7.5   0.36     8.3    13.5  deflection

  Single-skin thickness required : 23.0 mm
  Equivalent GRP thickness       : 7.8 mm
  HDPE/GRP thickness ratio       : 2.96 x
  Single-skin areal mass         : 21.8 kg/m2
  -> single skin on 33 m2 would weigh 710 kg. Not viable.

  DOUBLE SKIN: 5.0 mm skins, 50 mm gap, kiss-offs at 75 mm
  panel             t_equiv    need  face MPa  skin req   verdict
  bottom               42.2    23.0      1.44       4.3      PASS
  side                 42.2    21.2      1.14       4.0      PASS
  deck                 42.2    17.2      0.53       2.8      PASS
  cockpit_sole         42.2    13.5      0.32       2.8      PASS
  Areal mass: 9.5 kg/m2  (0.44x the single-skin mass)
  All panels pass: True

==============================================================================
3. WEIGHT BUDGET  (750 kg cap, light incl. ballast)
==============================================================================
item                                     kg    z (m)      kg.m   note
------------------------------------------------------------------------------------------------------
HDPE shell (hull+deck)                346.3    0.420     145.4   9.5 kg/m2 x 32.5 m2
keel case + pivot structure            22.0    0.350       7.7   welded PE bosses, bolted
rudder + tiller (single, kick-up)      15.0    0.550       8.2   centreline transom-hung; client amendment 2026-08-06
mast + boom + standing rig             32.0    3.100      99.2   short mast, no backstay
sails (main + jib + furler)            16.0    2.200      35.2   square-top, lazy bag
deck hardware + 2:1 systems            19.0    0.780      14.8   no winches
electric motor                         26.0    0.550      14.3   ~4 kW outboard format
battery                                31.6    0.220       6.9   3.0 kWh LiFePO4
spray hood + cockpit tent              11.0    0.950      10.4   stowed
anchor, lines, safety gear             18.0    0.400       7.2   
keel ballast (lead)                   213.1   -0.860    -183.3   REMAINDER of the 750 kg cap
------------------------------------------------------------------------------------------------------
LIGHT (incl. ballast)                 750.0    0.222
LOADED (6 crew + water)              1730.0    0.540

  Like-for-like against the RS Aira, backed out from its published figures:
    Aira shell mass, implied  : 367 kg  (GRP)
    This shell, HDPE double   : 346 kg
    Material penalty          : -21 kg   <- HDPE is roughly weight-neutral here
    Electric drive adds       : +58 kg   <- this is what costs the ballast

  Ballast available           : 213 kg
  Ballast ratio               : 28.4 %
  RS Aira 22 (GRP) for compare: 250 kg = 33.3 %
  Ballast delta vs Aira       : -37 kg

==============================================================================
4. HYDROSTATICS
==============================================================================
  LIGHT   disp  750.0 kg   draft 0.217 m   z_wl 0.217 m   LCB 2.20 m   Awp 7.26 m2   TPc 74.4 kg/cm   VCG 0.222 m
  LOADED  disp 1730.0 kg   draft 0.329 m   z_wl 0.329 m   LCB 2.31 m   Awp 9.25 m2   TPc 94.8 kg/cm   VCG 0.540 m

==============================================================================
5. SELF-DRAINING COCKPIT  (notes.txt line 30, the open question)
==============================================================================
  light ship               waterline z=0.217  sole z=0.385  freeboard to sole   +168 mm  -> drains
  6 crew + water ballast   waterline z=0.329  sole z=0.385  freeboard to sole    +56 mm  -> drains
  Sheer freeboard, light : 0.538 m

==============================================================================
6. RIGHTING ARM CURVES
==============================================================================
  case                 GZmax   @deg     AVS   A(0-90)  neg area  self-right
  light/intact         0.667     46   113.0     0.760     0.334       False
  light/flooded        0.667     46   112.2     0.754     0.320       False
  loaded/intact        0.383     36    88.4     0.374     0.474       False
  loaded/flooded       0.382     34    85.2     0.328     0.440       False

  Downflooding angle (cockpit opening immerses): 37.0 deg
  Beyond that angle only the 'flooded' curve is physically meaningful.

==============================================================================
7. SELF-RIGHTING VERDICT  (the stated requirement)
==============================================================================
  Requirement: recover unaided from 180 deg (fully inverted).
  Governing case: light/flooded -- crew are in the water, cockpit is full.

  RESULT: NOT self-righting.
    AVS                     112.2 deg
    Stable inverted?        yes -- GZ is negative approaching 180 deg
    Energy holding inverted 0.320 m.rad
    Ballast ratio           28.4 %

  Reference points (neither self-rights from 180 deg either):
    Contessa 26, fully decked, GRP           ballast ratio ~43 %, AVS ~157 deg
    RS Aira 22, fully decked, GRP            ballast ratio 33 %, not self-righting
  Note: the open cockpit is NOT the main culprit. Sealing it entirely
  moves AVS by about a degree (see trade study section 4), because when
  inverted the boat floats so high that the cockpit is mostly out of
  the water anyway. The binding constraint is beam-to-depth ratio:
  2.35 m beam on 0.75 m of depth is a hull that is stable upside down.

==============================================================================
8. SAIL-CARRYING CAPACITY
==============================================================================
  Upwind sail area  22.0 m2  (main 14.0 + jib 8.0)
  SA/D ratio        15.5   (18-20 brisk daysailer, >22 overpowered)

    true wind    tanks symmetric    windward tank only
         8 kt              2 deg                 0 deg
        12 kt              5 deg                 1 deg
        16 kt             10 deg                 5 deg
        20 kt             17 deg                12 deg
        25 kt             27 deg                25 deg
  Wind at peak righting moment: 28 kt symmetric, 30 kt with the windward tank  (gusts arrive sooner)
  One tank to weather = 250 kg at 0.65 m: about the righting moment of 2 crew on the rail

==============================================================================
9. ENVELOPE COMPLIANCE
==============================================================================
  LOA                       6.48 m   limit    6.50  ok
  Beam                      2.35 m   limit    2.50  ok
  Displacement (light)    750.00 kg  limit  750.00  ok
  Sail area upwind         22.00 m2  limit   22.00  ok
  Water ballast           487.80 L   limit  500.00  ok
  Draft, keel down          1.29 m   limit    1.30  ok

  Violations: 0

------------------------------------------------------------------------------
BASE MODEL PROVENANCE
------------------------------------------------------------------------------
  RS Aira 22 (published): LOA 6.5 m, beam 2.2 m, disp 750.0 kg, ballast 250.0 kg, sail 14.0+8.0 m2, GRP
  Flow 19 (from notes.txt, URL 403): beam 2.3 m, disp 450.0 kg, swing keel 70.0 kg, water ballast 2x60.0 kg

Report written to /Users/catalinahirsch/Desktop/bote/out/report.txt

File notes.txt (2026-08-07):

HDPE finalists
Dimensions
LOA <6.50
BEA <2.50
DIS <750
SQM <22
BAL <500
CBD <1.30

Shipyard QA
ISO Certification

Objective short
Request clear main ideas
Done well defined 

Aira 22
https://www.rssailing.com/project/rs-aira/
large cockpit 6 seats
bow cuddy no cabin, estante tela
furling jib
botavara alta, mástil corto, vela cuadrada

Flow 19
https://archinavale.carbonmade.com/projects/6600079
BEA 2.30 CND 1.30 DSP 450
70 kg swing keel
X2 60 kg water ballast
H francbordo y h piso cockpit ??
sin molinetes 2:1 purchase system
ruders pivotean
no traveler nor backstay

Notes:
open sailboat
reserva flotabilidad y auto-adrizante
x2 rudders short cane
pivot keel
rigging
electric engine

proa tomar sol
doble tambucho proa
cinturones piso xa adrizar quitapon
listón 1”x1” xa afirmar pie
spray hood
cockpit tent
self draining cockpit
cockpit desagota directo
popa semi-abierta

centered boom rig wo traveller
lazy bag main and auto furling jib
empty water ballast with air pump
fill water ballast while sailing (how?)
no backstay

3dm output format

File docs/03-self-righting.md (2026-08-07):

# Self-righting: the trade study

The brief asks for recovery from 180° unaided, in an open boat. This document
shows what that costs. Numbers come from `calc/trade.py` and `calc/options.py`;
raw output is in `out/trade_study.txt` and `out/options.txt`.

---

## 1. The test

A boat self-rights from fully inverted if and only if **GZ stays positive at
every angle up to 180°**. At exactly 180° the righting arm is zero by symmetry,
so the meaningful test is the sign just short of it: negative GZ approaching 180°
means there is a stable inverted equilibrium and the boat stays upside down.

The governing condition is **light ship with the cockpit flooded** — crew are in
the water, so their weight is not helping, and the cockpit is full.

## 2. Baseline result

| | |
|---|---|
| Ballast | 213 kg (28.4% ratio) |
| GZ max | 0.667 m at 46° |
| Downflooding angle | **37°** at full load (1730 kg) |
| AVS | **112°** |
| Stable inverted | **yes** |
| Energy holding it inverted | 0.32 m·rad |

**Not self-righting.** For reference: a Contessa 26 — the benchmark small
self-righting cruiser — has a ~43% ballast ratio, is fully decked, and reaches
AVS ~157°. It is *still* not self-righting from 180°. The RS Aira at 33% and
fully decked is not either.

### A note on which way the model errs

The flooded case removes the cockpit's buoyancy but does not add trapped water as
weight. That is right for a cockpit draining aft through an open transom at
moderate heel — the internal water level is the sea level. At large heel and
inverted, some water would sit above sea level and its weight would push GZ down
further.

Also visible in `out/gz_curves.png`: between roughly 60° and 110° the flooded
curve sits marginally *above* the intact one. That is real, not an error —
losing the cockpit's buoyancy makes the hull float deeper at the same heel, which
brings deck-edge volume on the low side into play and lengthens the righting arm
slightly. It reverses before the zero crossing, so flooded AVS still ends up
marginally below intact.

Both effects mean the model is **optimistic about self-righting**. The boat fails
the test anyway, so the conclusion below is robust in the direction that matters.

## 3. Which levers actually move it

### Ballast alone — no

At 2.35 m beam, adding lead barely helps:

| Ballast | Displacement | Ratio | AVS |
|---|---|---|---|
| 213 kg | 751 kg | 28% | 112° |
| 400 kg | 938 kg | 43% | 126° |
| 600 kg | 1138 kg | 53% | 136° |
| 1000 kg | 1538 kg | 65% | **149°** |

A tonne of lead on a 6.5 m hull, displacing ~1540 kg, still does not get there.
Ballast has strongly diminishing returns against inverted form stability.

### Sealing the cockpit — almost no effect

This is the counter-intuitive one. Fully decking the boat, so the cockpit is
watertight all the way round:

| Ballast | AVS flooded | AVS sealed |
|---|---|---|
| 213 kg | 112.2° | 112.4° |
| 300 kg | 119.6° | 119.9° |
| 400 kg | 126.3° | 126.2° |

**About one degree.** When inverted, light displacement against a large enclosed
volume means the boat floats very high — the cockpit is mostly above water
regardless of whether it is sealed. Narrowing the cockpit to convert floodable
volume into sealed side tanks does nothing measurable either (the cockpit-width sweep
moves AVS by ~1°).

So the common argument — *an open boat can't self-right because it floods* — is
not what is happening here. The boat would not self-right if it were decked.

### Water ballast — the answer depends on tank height

Where the tanks sit decides whether filling them helps or hurts at large heel.
Tanks **under the sole** (centroid z ≈ 0.26) are high above the water when
inverted, so full tanks destabilise the upside-down equilibrium — the RNLI
righting-tank mechanism — worth about +4° of AVS. But the client's decision to
build the tanks **into the bench seats** (centroid z ≈ 0.48, close to the roll
axis) inverts the trade: the upright VCG penalty now dominates.

With bench tanks, light ship + sealed-full tanks, flooded:

| Water aboard | Displacement | AVS |
|---|---|---|
| 0 | 750 kg | 111.0° |
| 250 kg | 1000 kg | 107.3° |
| **500 kg** | 1250 kg | **105.0°** |

So with seats-as-tanks there is **no heavy-weather argument for filling both
tanks** — symmetric fill costs ~6° of AVS and buys only damping. The tanks earn
their keep empty (reserve buoyancy, seats) or filled to windward (~two crew of
righting moment). Either way the effect is single-digit degrees against the ~70°
the requirement needs; it does not change the verdict.

### Beam — this is the constraint

Ballast held at the 213 kg the budget allows:

| Beam | GZ max | AVS | Energy holding inverted |
|---|---|---|---|
| 1.80 m | 0.441 m | **138°** | 0.035 m·rad |
| 1.95 m | 0.503 m | 123° | 0.110 m·rad |
| 2.10 m | 0.583 m | 117° | 0.189 m·rad |
| 2.35 m | 0.667 m | 112° | 0.317 m·rad |
| 2.50 m | 0.716 m | 110° | 0.384 m·rad |

Beam buys upright stiffness (GZ max rises with beam) and pays for it with
inverted stability. That is the same physics, read in both directions.

### The frontier

Minimum ballast for true self-righting, by beam:

| Beam | Ballast needed | Displacement | Ratio |
|---|---|---|---|
| 1.70 m | 383 kg | 920 kg | 42% |
| **1.75 m** | **417 kg** | **954 kg** | **44%** |
| **1.80 m** | **452 kg** | **988 kg** | **46%** |
| 1.90 m | 647 kg | 1184 kg | 55% |
| 2.00 m | 842 kg | 1379 kg | 61% |
| 2.10 m | 1059 kg | 1596 kg | 66% |
| 2.20 m | 1352 kg | 1889 kg | 72% |
| **2.35 m (as designed)** | **not achievable below 1400 kg** | — | — |

The curve is steep — roughly 200 kg of lead per 100 mm of beam above 1.80 m —
and past 2.10 m it runs away entirely. (These thresholds moved up ~90 kg when
the bench-tanks became sealed seats and the single rudder lightened the ends:
verdicts near 180° are sensitive to small changes, which is itself worth
knowing.)

## 4. Four ways to resolve it

### Option A — masthead buoyancy: prevent inversion rather than cure it

A 45–60 litre masthead float (≈2.5 kg) makes 180° unreachable. The boat stops at
roughly the AVS angle (~112°), floats on its side, and the crew right it from
there using the floor straps already in the brief (`notes.txt` line 46,
*cinturones piso xa adrizar quitapon*).

- **Cost: 2.5 kg and some windage aloft. Nothing else in the brief moves.**
- **Does not meet the requirement as literally stated.** It is not self-righting;
  it is inversion-proof plus crew-righted.

### Option B — narrow the hull

1.75–1.80 m beam, 417–452 kg ballast, ~954–988 kg displacement.

- Meets the requirement.
- **Loses the 6-abreast cockpit.** At 1.80 m beam the cockpit is ~1.25 m wide
  inside the side tanks: 4 seated comfortably, 6 only in line.
- **Exceeds `DIS 750` by 27–32%.** At ~990 kg the boat is also past the EU
  750 kg unbraked-trailer threshold, so the trailer needs brakes.
- Sail area needs rechecking: 22 m² on a 1.80 m beam hull with a 46% ballast
  ratio is a stiffer boat but a narrower one, so it will heel earlier.

### Option C — crowned "turtle" deck

Sealed buoyancy that is high when upright is deep when inverted, and depth is
what generates the moment. This is exactly how an RNLI lifeboat self-rights: the
watertight wheelhouse is the righting device. With no cabin, a strongly crowned
deck is the nearest equivalent available.

| Deck camber | Beam | Ballast needed | Displacement |
|---|---|---|---|
| 0.15 m | 2.35 m | not achievable | — |
| 0.25 m | 2.35 m | not achievable | — |
| 0.35 m | 2.35 m | not achievable | — |
| 0.25 m | 2.10 m | not achievable | — |
| 0.35 m | 2.10 m | not achievable | — |

- **It does not work at any camber tested, at 2.35 m or 2.10 m of beam.** A
  crowned deck alone cannot rescue this hull.
- Fights the flat sunbathing foredeck (line 44), the cockpit tent (line 49), and
  raises the boom further.
- **Not recommended.** Listed because it is the mechanism people reach for, and
  it is worth seeing it fail with numbers attached.

### Option D — deeper canoe body plus moderate narrowing

| Beam | Depth | Sheer height | Ballast needed | Displacement |
|---|---|---|---|---|
| 2.00 m | ×1.30 | 0.99 m | 615 kg | 1152 kg |
| 2.10 m | ×1.45 | 1.10 m | 771 kg | 1308 kg |
| 2.10 m | ×1.30 | 0.99 m | 835 kg | 1372 kg |
| 1.90 m | ×1.20 | 0.91 m | 1003 kg | 1540 kg |

- Works, but every configuration is heavier than Option B for the same result.
- Freeboard grows, and windage and trailer height with it. At 1.10 m of sheer
  height a 6.5 m open boat starts to look like a very different vessel.

## 5. Recommendation

**The requirement and the brief are mutually exclusive.** The choice is:

1. **Keep the boat, change the requirement** → Option A. A 2.5 kg masthead float
   gives a boat that cannot invert and that the crew can always right, keeping
   the 6-seat cockpit, 750 kg, 2.35 m beam and 22 m² intact. This is what the
   floor straps in `notes.txt` line 46 already imply, and it is what
   *auto-adrizante* most plausibly meant.

2. **Keep the requirement, change the boat** → Option B at 1.80 m beam. Accept a
   4-seat cockpit and ~990 kg, and get genuine 180° recovery.

Options C and D are dominated by B on every axis.

If the answer is B, the parametric model already carries it:

```
python3 -m geom.hull --self-righting     # 1.80 m beam hull, STL + offsets
```

and the baseline in `calc/params.py` needs `beam_sheer = 1.80` and
`envelope.disp_max = 990`.

## 6. What is *not* in question

Everything else in the brief checks out at the baseline:

- Cockpit self-drains: +56 mm of sole freeboard with 6 crew and 500 L aboard
- Sail area is carryable: 15° steady heel at 20 kt (11° with the windward tank),
  peak righting moment at 32 kt
- Envelope compliance: 0 violations, including 488 L ≤ 500 L water ballast
- Structure: all HDPE panels pass, double-skin, 9.5 kg/m²

The self-righting requirement is the only thing that does not close.

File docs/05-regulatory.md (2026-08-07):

# Regulatory path — Argentina and Chile

What it takes to build, register and operate this boat legally in each country.
Grounded in the primary documents fetched 2026-08-06 (cited at the end); **this
is engineering research, not legal advice — confirm with the Prefectura /
Capitanía before cutting material**, because ordinances get amended and local
jurisdictions add requirements.

The two systems are structured differently and it changes what you build first:
**Argentina regulates the construction** (approval before and during the build,
signed by a registered professional); **Chile regulates the finished boat**
(local inspection, roll test, equipment). If the boat will live in both
countries, design the paperwork for Argentina and the equipment for Chile and
you satisfy both.

---

## 1. Argentina — Prefectura Naval Argentina (PNA)

Framework: Ley 20.094 (Navigation), REGINAVE (Decree 4516/73), Tomo 4
Ordenanza 1-18 (DPSN) "Régimen de las Actividades Náutico-Deportivas".

### 1.1 Construction approval

- Any individual construction gets a **Certificado de Aprobación de
  Construcción** from PNA; a repeatable design gets a **Certificado de
  Aprobación de Prototipo** (both defined in Ord. 1-18 §1). If you intend to
  build more than one boat for clients, do the prototype approval once — every
  later hull rides on it.
- The project must be signed by a professional (naval engineer / licenciado /
  técnico constructor naval) under a **Certificado de Encomienda** — the
  contract of technical representation (Ord. 1-18 §1, definitions). The
  designer and the construction supervisor must be registered with the
  professional council (CPIN) and with PNA (REGINAVE Título 1, art. 101.0302).
- Submission: plans (general arrangement, lines, structure/midship section,
  electrical, bilge), calculation memory (weights, stability), materials. This
  repo *is* most of the technical annex: offsets, 3DM, scantlings with method,
  weight/VCG budget, GZ curves, equipment schedule.
- **HDPE note:** PNA's technical rules, like ISO 12215, have no rotomoulded-PE
  scantling table. Expect the Agrupación Técnica to ask for equivalence
  justification — the plate-theory + creep-derated-modulus method in
  `calc/scantlings.py` plus panel test coupons is the standard argument. Budget
  time for this conversation; have the ingeniero naval lead it.

### 1.2 Registration and zone

- Registration in **REJU** (Registro Jurisdiccional — typical for a 6.5 m open
  daysailer) or **REY** (Registro Especial de Yates).
- The boat's permitted **navigation zone** is set in its construction
  certificate (Ord. 1-18 §4.1): Aguas Protegidas / Costera Restringida /
  Costera Marítima / Oceánica. **Target: Costera Restringida** (protected +
  limited coastal) — consistent with design category C assumptions in the
  stability work. Oceánica is off the table for an open boat and was never the
  brief.
- Skipper licence: a 6.48 m auxiliary-sail yacht needs **Timonel de Yate a
  Vela** minimum (Ord. 1-18 §7.2.4); Conductor Náutico only covers motor boats
  to 7 m. Tell the client — it affects who they can sell/lend the boat to.

### 1.3 Equipment (Ord. 1-18 Anexo A, VELA column, Costera Restringida / Aguas Protegidas)

| Item | Costera Restringida | Aguas Protegidas |
|---|---|---|
| Lifejackets (all aboard) | ✔ | ✔ |
| Anchor + line — **6.0–8.9 m boat: 7 kg anchor, 12 mm nylon, 6 mm chain** (§4.7) | ✔ | ✔ |
| Compás magnético | ✔ | ✔ (vela) |
| VHF (portable OK; cell phone w/ GPS acceptable in these zones) | ✔ | ✔ |
| Hand sonda / lead line | ✔ | ✔ |
| Manual bilge pump (§4.6) + bailer | ✔ | bailer |
| Fire extinguisher (tri-class, sized to boat) | ✔ | ✔ |
| Nav lights per RIPA | ✔ | ✔ |
| Bell or hand bell (≤12 m), horn/whistle | ✔ | ✔ |
| Red hand flares ×2, parachute ×2 (hand-only on large lakes) | ✔ | flares ×2 |
| Lifebuoy w/ 27.5 m floating line | ✔ | ✔ |
| First-aid kit (Anexo A **) | ✔ | ✔ |
| Signal mirror, distress-signal table, RIPA text | ✔ | ✔ |
| Harnesses (per boat size) | ✔ | — |
| Cizalla (rigging cutter) — **sail specific** | ✔ | ✔ |

(EPIRB, raft, AIS, HF, sextant: Oceánica only — not applicable.)

### 1.4 Design consequences already absorbed

- Manual bilge pump is in the spec (§8 of the build spec) even though the
  cockpit is self-draining.
- Anchor spec fixed at 7 kg / 12 mm / 6 mm chain per the §4.7 table.
- Rigging cutter (cizalla) added to inventory — a dismasted rig with no
  backstay still needs cutting free.

## 2. Chile — DIRECTEMAR / Autoridad Marítima

Framework: D.L. 2.222 (Ley de Navegación), D.S. 87/97 + D.S.(M) 214/2015
(Deportes Náuticos), **Circular O-71/010** (construction/inspection of naves
menores), **Circular A-41/014** (equipment for embarcaciones deportivas).

### 2.1 Construction and plan approval — lighter than Argentina

- Registration of naves menores deportivas is at the **Capitanía de Puerto**;
  boats under 5 m sail-only are exempt — at 6.48 m this boat **must register**
  (A-41/014 II.C).
- For an **open (undecked) boat**, O-71/010 Anexo A(C) requires only a **croquis
  with the principal hull data and measurements** plus 4 photos showing name
  and registration on the hull; project review, where sought, is done locally
  by the **SCLINM** (local minor-vessel inspection commission). Formal plan
  sets are for ≥12 m or decked vessels.
- Stability for <12 m: **initial stability only, by rolling-period test** on
  the finished boat (O-71/010 Anexo B.2, per the fishermen's-code Annex III
  method). This is the §10.9 test in the build spec. No paper GZ submission is
  demanded — but ours exists and makes the inspection conversation short.
- **Certificado de Navegabilidad** after inspection; 6-year validity for
  deportivas menores (A-41/014 II.D) with the owner responsible for keeping
  equipment current.

### 2.2 Classification and the two flags to manage

- Likely classification: **Bahía (vela)** or **Costera 12 MN** depending on
  where the client sails. Equipment differs sharply (below).
- **Ballast must be permanently installed** (A-41/014 II.K.1). A pivoting keel
  bolted through cheek plates qualifies; **pumpable water ballast is arguably
  not "permanent"** — this is the one genuine regulatory friction point in the
  design. Position it to the Capitanía as trimming/ballast *tanks* integral to
  the structure (they are welded-in bench tanks, not portable weights), with
  the operating rule documented. Get this agreed **before** the build, in
  writing. Fallback if refused: the boat floats on its lines with tanks empty;
  ballast function is then windward trim only, or tanks get filled and sealed
  permanently at a reduced 120 kg (which restores the original Flow-19 spec).
- **Sails**: no furling main → main must reef ≥40% of luff (A-41/014 II.M) —
  the 2 reef rows in the build spec §2 satisfy this. Furling jib satisfies the
  headsail clause.
- Sail-powered costeras must carry an **auxiliary motor** (II.H) — the electric
  outboard satisfies it; note II.H.2: if the motor is inoperative, coastal
  boats are limited to 12 MN.

### 2.3 Equipment (A-41/014 Anexo A)

**Bahía Vela** (protected-water sailing): lifejackets for all (ISO 12402-4,
100 N), cell phone in waterproof case, alternative bailing system, compass (R),
anchor per design, lifejackets worn **at all times** in bahía class (II.L.8).

**Costera 12 MN** adds: VHF with DSC (portable acceptable), GPS, 150 N
lifejackets (ISO 12402-3), harnesses, 2+2 flares, extinguisher, manual bilge
pump, charts, lifebuoy with light, first-aid kit per Anexo B, compass and
corredera mandatory, EPIRB replaceable by satellite tracker (II.G.2).

Life raft: only required for costeras **outside bay limits** (II.L.1) — for
12 MN operation plan on carrying one or staying classified Bahía.

### 2.4 Registration papers

Owner must be Chilean (or per Ley de Navegación art. 11 conditions); sail
number certificate from the **Federación de Vela de Chile**; title documents;
name + registration painted per II.E (amuras: port abbreviation + number,
aletas: name, espejo: home port) — the 4 photos for the croquis file show
exactly this.

## 3. The cross-border summary

| | Argentina | Chile |
|---|---|---|
| Before building | **Yes** — project + Encomienda + CPIN professional, PNA approval | No (open boat <12 m: croquis + local SCLINM at most) |
| During building | Supervision by registered professional | Optional SCLINM supervision on request |
| After building | Construction certificate → REJU/REY registration | Roll test + inspection → matrícula + Cert. de Navegabilidad |
| Stability proof | Calculation memory in the project | **Roll-period test on the water** |
| Water ballast | Part of the approved project | **Negotiate "permanent installation" reading first** |
| Skipper | Timonel de Yate a Vela | Licencia deportiva per class |
| Sail detail | — | Main: ≥40% reefable ✔ (2 reefs) |
| Equipment driver | Ord. 1-18 Anexo A by zone | Circular A-41/014 Anexo A by class |

**Actionable order:** (1) engage the ingeniero naval in Argentina and submit
the project; (2) in parallel, put the water-ballast question to the Chilean
Capitanía in writing; (3) build; (4) roll test — it serves both the Chilean
certificate and the model validation.

## Sources

- [PNA Ordenanza 1-18 (DPSN), Tomo 4 — Régimen de las Actividades Náutico-Deportivas](https://www.ingsa.com.ar/pdf/3a30f2463c14fe25d5865cc30845e51038b6a3d0.pdf) (definitions §1; zones §4.1.2; bilge §4.6; anchor table §4.7; equipment Anexo A; licences §7.2)
- [PNA Ordenanza 4-09 (DPSN)](https://www.argentina.gob.ar/sites/default/files/4-2009-4.pdf) (use authorizations — context only)
- [PNA — Preguntas frecuentes deportes náuticos](https://www.argentina.gob.ar/prefecturanaval/deportesnauticos/preguntas-frecuentes)
- [DIRECTEMAR Circular A-41/014 (2019)](https://www.directemar.cl/directemar/site/docs/20170328/20170328153044/circular_a_41_014_publicada.pdf) (construction reference II.B; inscription II.C; navegabilidad II.D; ballast II.K; sails II.M; equipment Anexo A/B)
- [DIRECTEMAR Circular O-71/010](https://www.directemar.cl/directemar/site/docs/20170130/20170130125617/o71_010_publ.pdf) (plan requirements Anexo A; arqueo/estabilidad Anexo B — roll test for <12 m; open-boat croquis clause)
- [DIRECTEMAR — Inscripción de naves menores deportivas](https://www.directemar.cl/directemar/tramites/inscripcion-de-naves-menores-deportivas)
- [DIRECTEMAR TM-078 — Manual de inscripción de naves](https://www.directemar.cl/directemar/site/docs/20170829/20170829144922/tm_078_actualizado_11_abr_2024.pdf)

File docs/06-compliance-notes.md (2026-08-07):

# Compliance matrix — notes.txt (client requirements)

Every line of `notes.txt` checked against the design as specified in
`04-build-spec.md`. Status: ✅ met · ⚠️ met with a caveat the client should see ·
❌ not met, decision needed · ➖ not a requirement (note-to-self in the file).

| Line | Requirement | Status | Where / how |
|---|---|---|---|
| 1 | HDPE material ("HDPE finalists") | ✅ | Rotomoulded HDPE double skin 2×5 mm/50 mm; welded PE500 prototype route. Weight-neutral vs GRP (report §3). Build spec §2–3. |
| 3 | LOA < 6.50 | ✅ | 6.48 m |
| 4 | BEA < 2.50 | ✅ | 2.35 m (road-trailerable) |
| 5 | DIS < 750 | ✅ | 750.0 kg light incl. ballast — at the cap exactly, tolerance −25/+0 kg in build spec §1 |
| 6 | SQM < 22 | ✅ | 22.0 m² (14 main + 8 jib) — at the cap |
| 7 | BAL < 500 (500 L water ballast) | ✅ | 488 L (2 × 244 L) in the bench-tanks |
| 8 | CBD < 1.30 | ✅ | 1.29 m keel down (to bulb bottom, audited) |
| 10 | Shipyard QA | ⚠️ | Build spec §10: wall-thickness ultrasonic audit, tank leak test, inclining test. A yard-level QA plan (weld inspection records, material certs) is sketched, not written — say the word and it becomes a checklist. |
| 11 | ISO certification | ⚠️ | ISO 12215-5 has **no rotomoulded-PE path**; scantlings follow its pressure *form* with equivalence justification — the accepted route, but it is testing + argument, not a checkbox (design spec §6). Stability: ISO 12217-2 methods used in the model. AR/CL law does not require ISO; see docs/05. |
| 13–15 | "Objective short / clear ideas / done well defined" | ➖ | Notes-to-self on scoping. The repo's structure (requirements → spec → build → regulatory) is the response. |
| 17–18 | Base: RS Aira 22 | ✅ | Envelope, 6-seat cockpit, rig concept, published specs used throughout (docs/01 §1) |
| 19 | Large cockpit, 6 seats | ✅ | 3.20 × 1.72 m cockpit; two 3.2 m benches seat 3 per side. ⚠️ see operating rule: with 6 crew, tanks stay empty (loaded AVS). |
| 20 | Bow cuddy, no cabin, fabric shelf | ✅ | Cuddy forward of x = 5.05 m under the foredeck, `estante tela` in materials (build spec §2). |
| 21 | Furling jib | ✅ | 8 m² on furler — also satisfies Chile A-41/014 II.M headsail clause |
| 22 | High boom, short mast, square-top main | ✅ | Boom **1.80 m** above baseline — audited: 1.0 m over the bench tops clears a tall seated adult; 1.66 m did not. Mast 8.60 m; square-top main. ⚠️ square-top + no backstay = swept spreaders, standard but tune matters (build spec §6). |
| 25–27 | Base: Flow 19 (BEA 2.30, draft 1.30, DSP 450) | ✅ | Ballast strategy and purchase system taken (its twin rudders were dropped by client amendment); figures unverified (URL 403) — flagged in docs/01 §1 |
| 28 | ~70 kg swing keel (Flow 19 reference) | ⚠️ | Our pivot keel is 213 kg total. The 70 kg Flow-19 keel scaled to this displacement and to any meaningful AVS is too light; 213 kg is what the 750 kg budget allows. Client should know it departs from the Flow 19 number deliberately. |
| 29 | 2 × 60 kg water ballast (Flow 19 reference) | ✅→ | Superseded by client: BAL < 500 read as 500 L → 2 × 250 kg fitted. |
| 30 | Freeboard / cockpit sole height "??" | ✅ | **Resolved by calculation**: sole 0.385 m → +168 mm light, +56 mm at 1730 kg full load. Report §5. Tightest number in the boat; sole tolerance +10/−0. |
| 31 | No winches, 2:1 purchase | ✅ | All controls 2:1 (keel lift 4:1 tackle), no winches (build spec §6) |
| 32 | Pivoting rudders | ✅ | Kick-up rudder, transom-hung. **Client amended to a single rudder (2026-08-06)** — pivoting requirement kept. |
| 33 | No traveller, no backstay | ✅ | Centreline mainsheet beam; swept spreaders replace backstay. Hard-point engineering in build spec §4. |
| 37 | Open sailboat | ✅ | Open self-draining cockpit, no cabin |
| 38 | Reserve buoyancy + self-righting (`auto-adrizante`) | ❌/⚠️ | Reserve buoyancy ✅ — sealed bow cuddy + sealed bench-tanks + double-skin voids; the boat floats swamped. **True self-righting from 180° is NOT met and cannot be within this brief** (beam-dominated; docs/03). Options: masthead float + crew righting (keeps everything else), or 1.80 m beam variant (loses 6-abreast + 750 cap). **Client decision required — the one open item.** |
| 39 | 2 rudders, short tillers | ✅→ | **Client amended to one rudder with short tiller (2026-08-06)**, superseding this line |
| 40 | Pivot keel | ✅ | x = 3.30 m pivot, 0.30/1.29 m drafts, hold-down latch |
| 41 | Rigging | ✅ | Full rig dimensions I/J/P/E in build spec §6 |
| 42 | Electric engine | ✅ | 4 kW outboard + 3 kWh LiFePO₄. ⚠️ costs 58 kg ≈ 46 kg of ballast vs the Aira — the honest price of electric (report §3). |
| 44 | Sunbathing foredeck | ✅ | Flat foredeck kept — one reason the turtle-deck self-righting option was rejected (docs/03 §4C) |
| 45 | Double bow hatch | ✅ | Specified: two gasketed PE-framed acrylic hatches on the cuddy top (not yet drawn in the 3DM — arrangement detail for the tooling pass) |
| 46 | Floor straps for righting, removable | ✅ | Webbing straps on sole anchors; part of the crew-righting concept that pairs with the masthead float option |
| 47 | 1"×1" foot batten | ✅ | Welded PE batten on the sole centreline (weldable = trivial in HDPE) |
| 48 | Spray hood | ✅ | On cuddy aft edge; 11 kg budget line covers hood + tent |
| 49 | Cockpit tent | ✅ | Boom-ridge tent over the 1.80 m boom — the high boom makes this work |
| 50–51 | Self-draining cockpit, direct drain | ✅ | Sole above WL at full load; drains aft through transom — no valves to fail |
| 52 | Semi-open transom | ✅ | Transom open above sole level between rudder stocks |
| 54 | Centred boom rig w/o traveller | ✅ | Mainsheet to centreline beam under sole |
| 55 | Lazy bag main + auto furling jib | ✅ | Build spec §2. Main has 2 reef rows — **required by Chile** (A-41/014 II.M) since the main doesn't furl. |
| 56 | Empty water ballast with air pump | ✅ | 12 V diaphragm pump pressurises tank via vent; also gravity dump when heeled (build spec §7) |
| 57 | Fill water ballast while sailing — "how?" | ✅ | **Resolved**: forward-facing Ø38 scoop at the chine per side, ball valve; fills 244 L in ~3 min above 4 kt, zero electrical load. Cross-connect line allows tacking the ballast. |
| 58 | No backstay | ✅ | Duplicate of 33 |

## Summary for the client

**Met: 30 of 33 requirement lines.** The three that need their eyes:

1. **Line 38, self-righting — the only ❌.** Physics, not effort: at 2.35 m beam
   no ballast the boat can float will bring it back from 180°. Two honest
   resolutions on the table (docs/03 §5); the rest of the boat is unaffected by
   either. This decision should be made before tooling.
2. **Line 11, ISO** — achievable as *equivalence + testing*, not as a stamped
   checklist, because no ISO scantling standard covers rotomoulded PE. Cost and
   schedule item.
3. **Line 19/7 interaction** — 6 crew and full tanks don't stack (AVS 85°
   loaded). The operating rule (crew full → tanks empty) is now part of the
   design and should be on a placard at the fill valves.

Plus one regulatory flag outside the notes: **Chile requires ballast to be
"permanently installed"** — get the Capitanía's written agreement on the
welded-in tanks before building (docs/05 §2.2).

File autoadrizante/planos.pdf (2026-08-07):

## L1 · Disposicion general

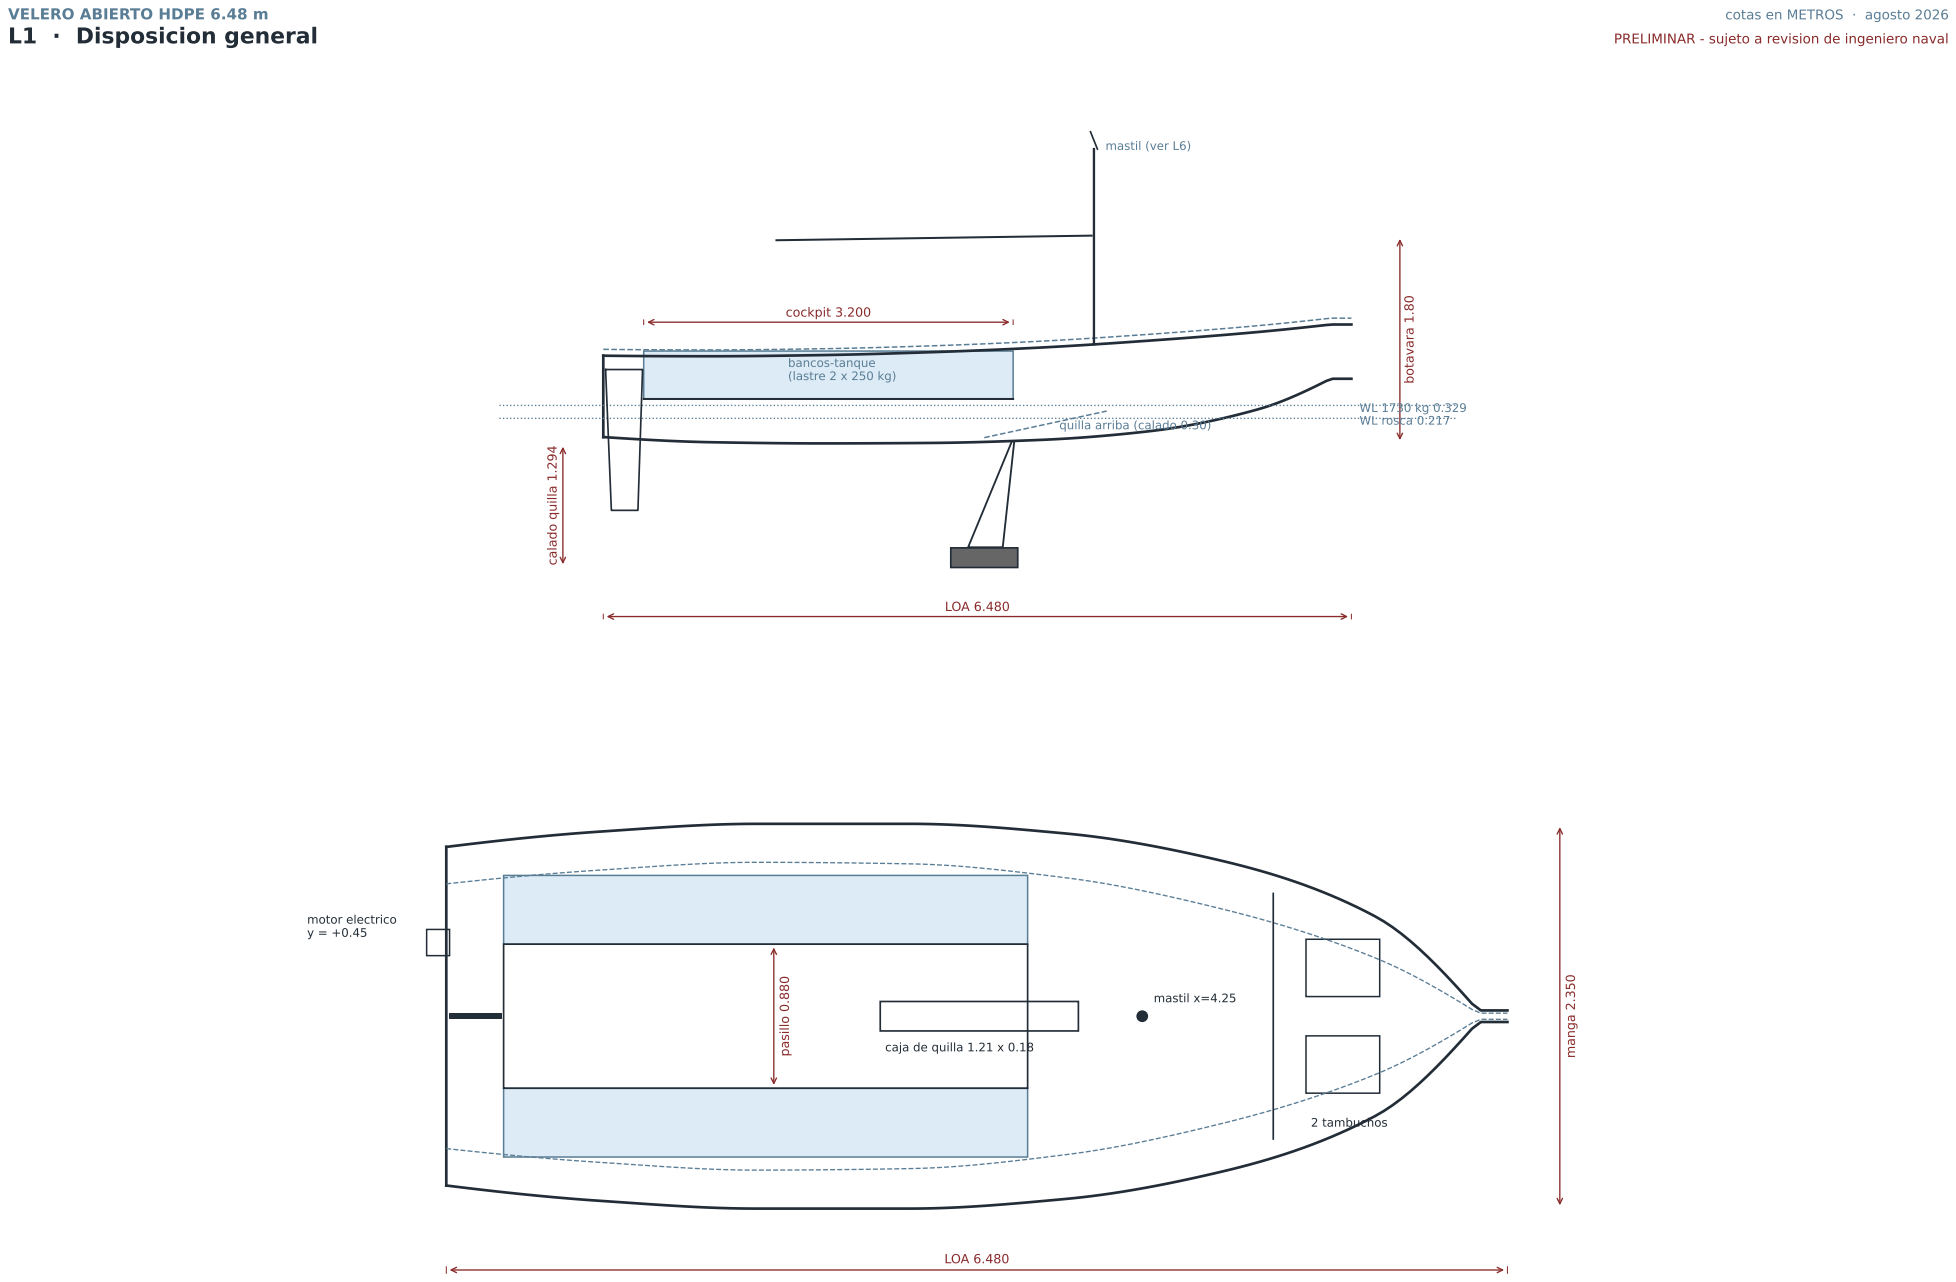
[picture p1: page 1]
WL rosca 0.217; bancos-tanque (lastre 2 x 250 kg); mastil (ver L6); botavara 1.80; calado quilla 1.294; LOA 6.480; cockpit 3.200; 2 tambuchos; mastil x=4.25; motor electrico y = +0.45; pasillo 0.880; manga 2.350

VELERO ABIERTO HDPE 6.48 m

cotas en METROS · agosto 2026

PRELIMINAR - sujeto a revision de ingeniero naval

quilla arriba (calado 0.30)

caja de quilla 1.21 x 0.18

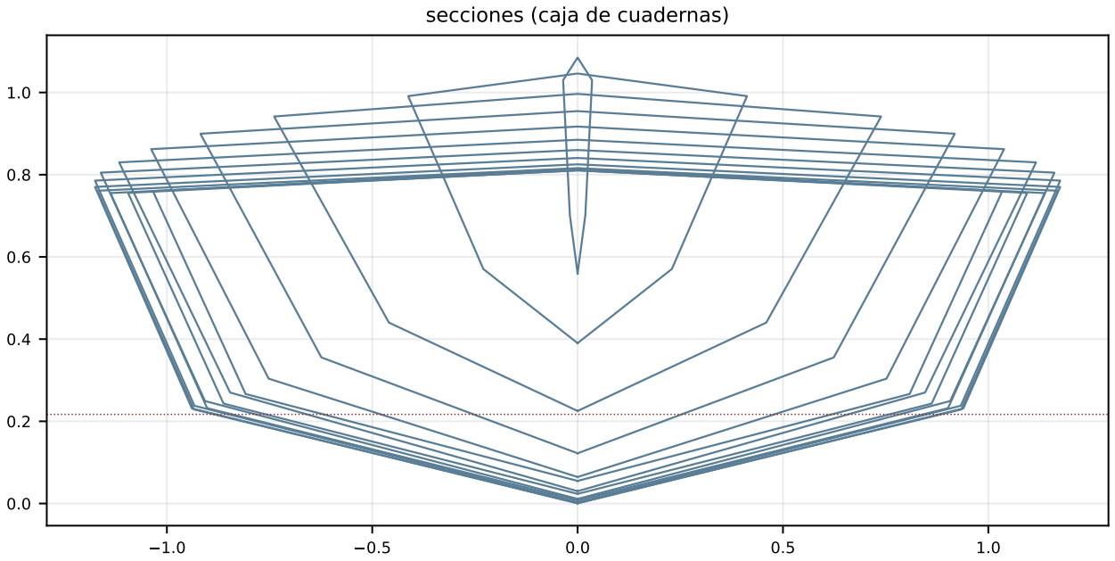
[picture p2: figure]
secciones (caja de cuadernas)

0 | 1 | 2 | 3 | 4 | 5 | 6

0.00

0.25

0.50

0.75

1.00

perfil

quilla codaste

borda

## L2 · Plano de formas (tabla de puntos: offsets_autoadrizante.txt, 121 estaciones)

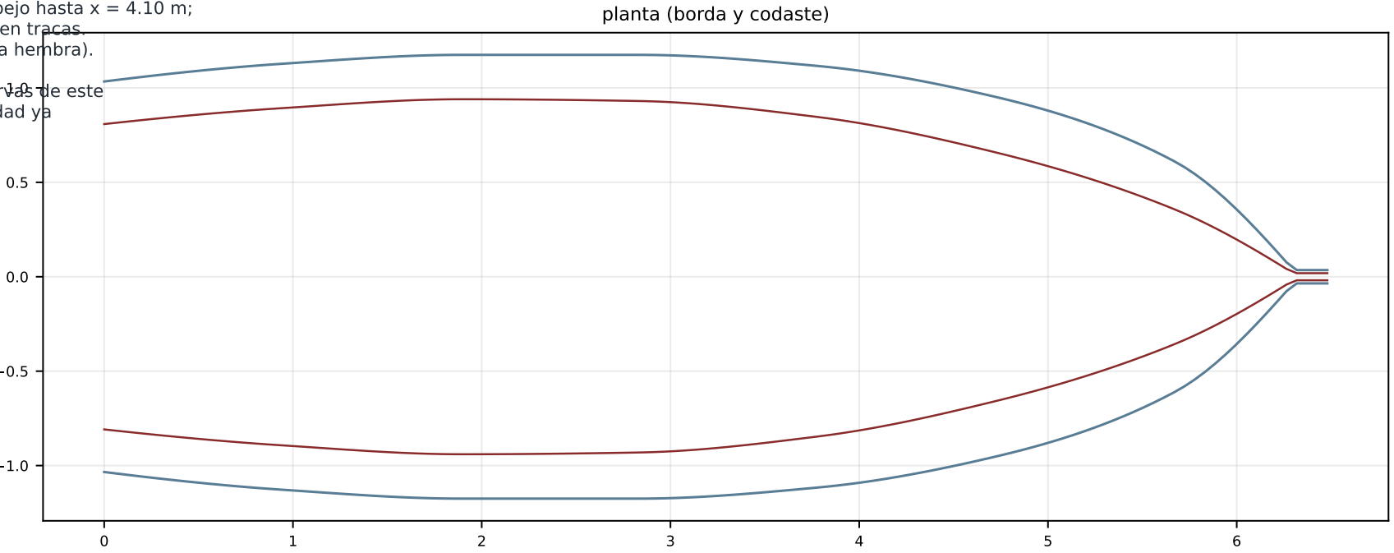
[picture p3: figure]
planta (borda y codaste)

Construccion en chapa: paneles desarrollables desde el espejo hasta x = 4.10 m; a proa, termoformar la roda sobre plantilla macho o dividir en tracas. Rotomoldeo: la desarrollabilidad es irrelevante (herramienta hembra).

Lofting: pasar splines por la tabla de puntos y alisar; las curvas de este plano son las del modelo de calculo (hidrostatica y estabilidad ya verificadas sobre esta geometria).

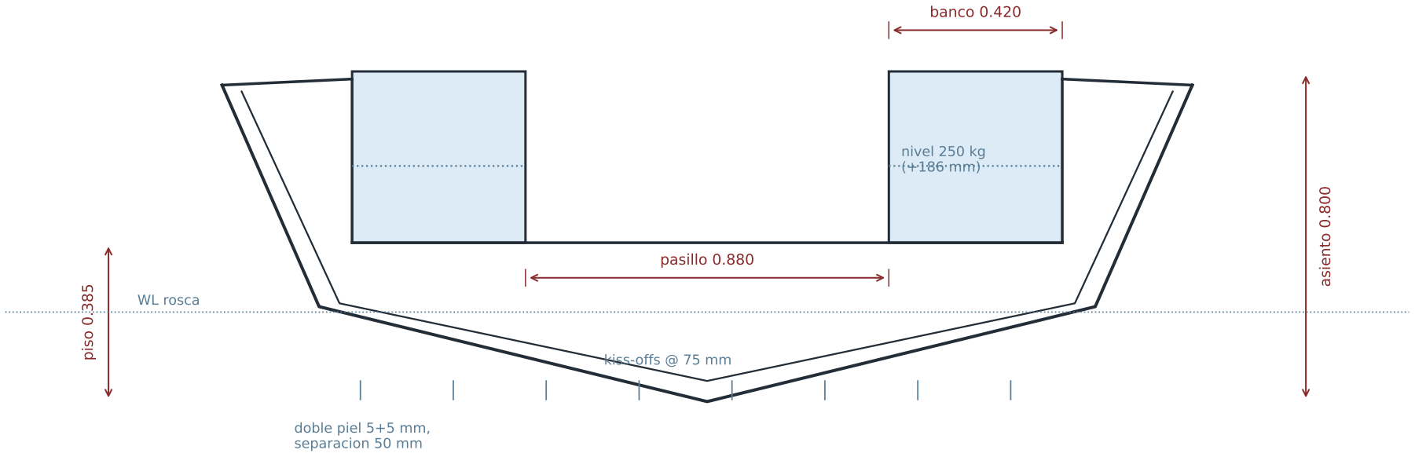
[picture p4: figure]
doble piel 5+5 mm, separacion 50 mm; kiss-offs @ 75 mm; nivel 250 kg (+186 mm); piso 0.385; asiento 0.800; pasillo 0.880; banco 0.420; WL rosca

manga en seccion 2.350

## L3 · Seccion maestra constructiva (x = 2.00 m)

### LAMINADO (rotomoldeo)

- 2 pieles HDPE 5.0 mm (-0/+1)
- separacion 50 mm
- kiss-offs Ø60 @ 75 mm fondo/costado, @ 100 mm cubierta
- masa 9.5 kg/m2
- equivalente rigidez: 42 mm solidos

PROTOTIPO (chapa soldada)
- PE500 12 mm fondo/costados,
10 mm cubierta
- omegas PE 60x40x8 @ 200 mm
- cordon extrusion int.+ext. en borda
- (+40 kg vs rotomoldeo)

REGLA DE ORO
Nada se pega al HDPE: union = soldadura PE-PE o bulon A4 con placa 6082-T6 y tubo de compresion piel-a-piel. Dilatacion PE ~10x aluminio:
agujeros ovalados en tramos > 0.5 m.

Paredes de banco: PE 8 mm soldadas a piso y casco - son estructura (rigidizan el costado y portan el piso). Tapa registro con junta en cada banco.

pala 0.92

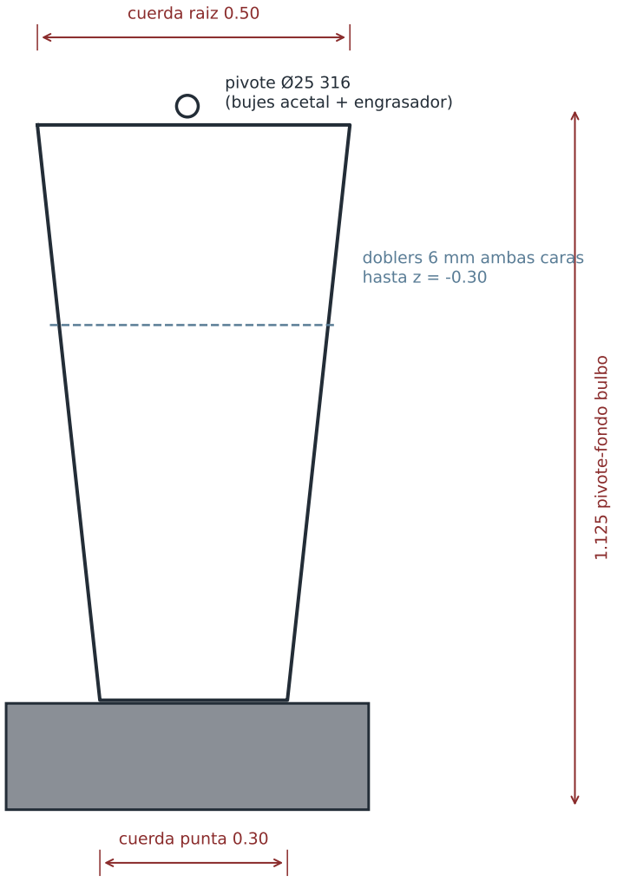
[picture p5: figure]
pivote Ø25 316 (bujes acetal + engrasador); doblers 6 mm ambas caras hasta z = -0.30; cuerda raiz 0.50; cuerda punta 0.30; 1.125 pivote-fondo bulbo

bulbo 0.580

## L4 · Quilla pivotante-retractil (auditada: calc/audit.py)

### DESPIECE Y MASAS

Pala: S355 15 mm, perfilada NACA 0012,
galvanizada en caliente | 50 kg
Bulbo: plomo fundido (2-4% Sb)
0.58 x 0.145 x 0.17 m (14.3 L) .... 163 kg centroide bulbo z = -0.99
CONJUNTO | 213 kg
VCG conjunto z = -0.86 (el que usa
el modelo de estabilidad)
Calado bajada: 1.294 m (tope CBD 1.30) Calado subida: 0.30 m

TENSIONES
Flexion raiz a RM max (4.9 kN.m):
157 MPa -> SF 2.3 sobre fluencia

CAJA
Ranura casco 1.21 x 0.18 m; caja PE 12 mm con placas laterales 6082-T6 8 mm,
8x M12 A4 pasantes con tubos.
Izado: aparejo 4:1 al cockpit.
TRABA de posicion bajada (obligatoria: una orzada no debe retraerla).

Fundicion del bulbo: molde de arena alrededor de la punta de la pala (taladros Ø20 x3 en la punta para llave mecanica plomo-acero).

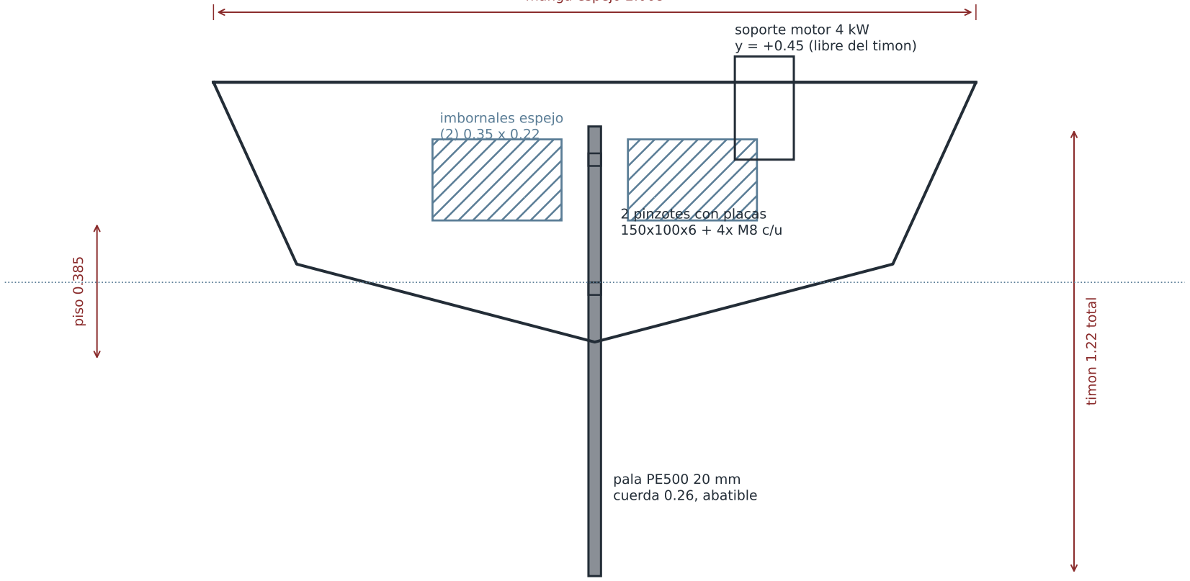
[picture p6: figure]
imbornales espejo (2) 0.35 x 0.22; pala PE500 20 mm cuerda 0.26, abatible; 2 pinzotes con placas 150x100x6 + 4x M8 c/u; soporte motor 4 kW y = +0.45 (libre del timon); piso 0.385; timon 1.22 total

manga espejo 2.068

## L5 · Espejo: timon unico abatible, imbornales y motor

### TIMON (enmienda del cliente: UNO)

- Central, colgado del espejo, abatible
(kick-up) con retencion por gomas o fusible; cana corta.
- Pala NACA 0010, cuerda media 0.26 m, inmersa 0.85 m (mas profunda que las gemelas que reemplaza: agarre a 20-25° de escora).
- Mecha 6082-T6; pinzotes pasantes con placas de respaldo (nunca roscar al PE).

ESPEJO SEMI-ABIERTO
- Drena el cockpit por gravedad; abertura partida a ambos lados de la mecha.
- El piso (0.385) queda +56 mm sobre la flotacion a plena carga: verifica el autoachique en la peor condicion.

MOTOR
- Electrico ~4 kW en soporte a y=+0.45 (estribor), placa de respaldo 6082-T6; bateria 48 V bajo el piso en caja ventilada y trincada.

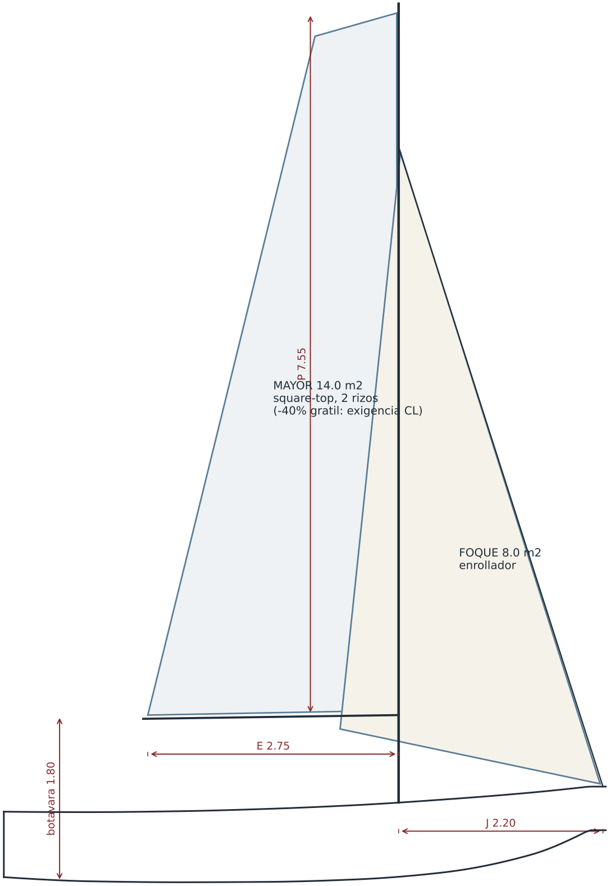
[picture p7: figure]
MAYOR 14.0 m2 square-top, 2 rizos (-40% gratil: exigencia CL); FOQUE 8.0 m2 enrollador; botavara 1.80

I 7.05

## L6 · Plano velico y jarcia

### JARCIA

Mastil 8.60 m, 6082-T6 ~110x2.5, pisado en cubierta sobre larguero 120x60x8 (3 mamparos PE).
Sin backstay ni traveller: crucetas retrasadas ~20°, pretension con ~20 mm de prebend.
Obenques + estay: 1x19 316 Ø5, cadenotes 50x8 a y=±1.10, x=4.05. Escota mayor 2:1 a punto fijo central (viga 80x40x4 bajo el piso, x=1.55, apoyada en paredes de bancos). Sin winches: todo 2:1; izado quilla 4:1.

BOTAVARA A 1.80 m
= 1.0 m sobre el asiento: pasa sobre cabezas sentadas (auditado; a 1.66 no pasaba). Sosten de carpa-toldo.

VELERIA
Dacron 250-300 g/m2; mayor con lazy bag; numeral por Federacion de Vela (CL) / PNA (AR).

cuchara Ø38 + valvula bola (orientada a proa, en codaste)

venteo Ø25
(cuello de cisne)

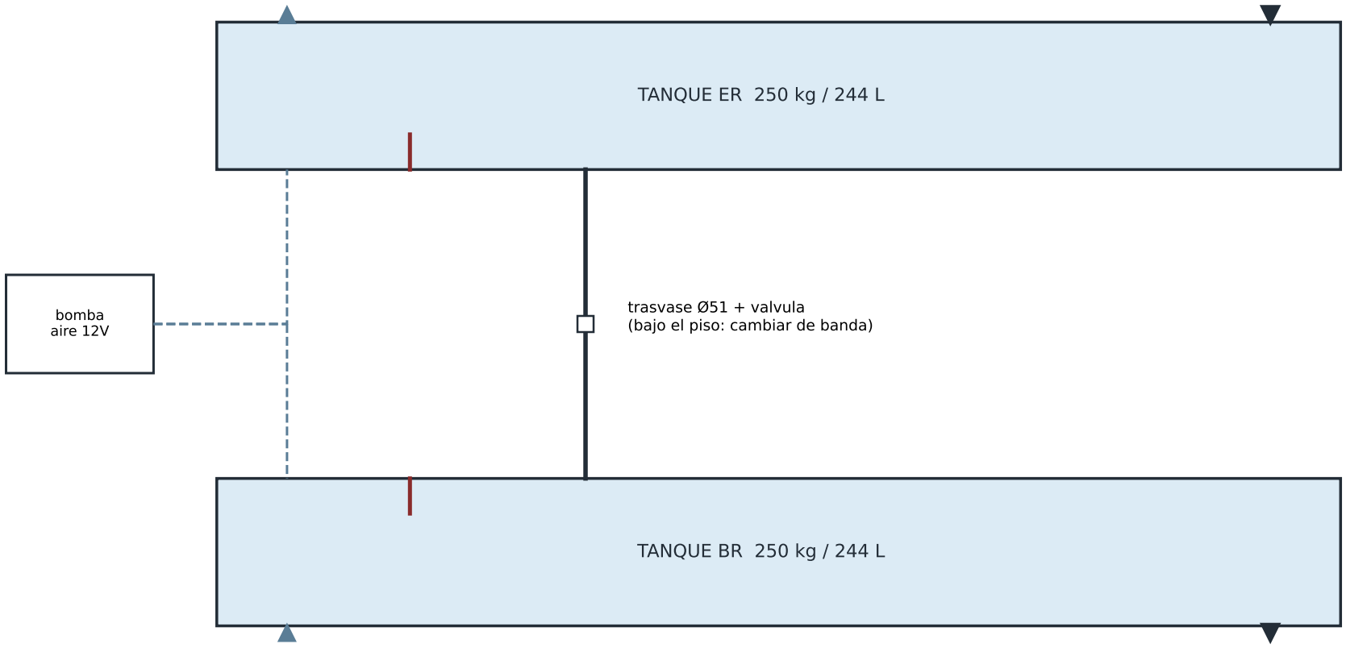
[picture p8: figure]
TANQUE ER 250 kg / 244 L; TANQUE BR 250 kg / 244 L; trasvase Ø51 + valvula (bajo el piso: cambiar de banda) bomba aire 12V

cuchara Ø38 + valvula bola
venteo Ø25 | (orientada a proa, en codaste)
(cuello de cisne)

## L7 · Sistema de lastre de agua (bancos-tanque) + placa operativa

### OPERACION

LLENAR (navegando > 4 kt): abrir valvula de cuchara de sotavento ~3 min; trasvasar a barlovento en la virada. VACIAR: bomba de aire presuriza por el venteo y expulsa por la cuchara; o descarga por gravedad escorado. SELLADO: tanques estancos probados a 0.15 bar (son la reserva de flotabilidad ademas del lastre).

### PLACA JUNTO A LAS VALVULAS (grabar):

TRIPULACION 5-6: TANQUES VACIOS · TRIPULACION 1-3: SOLO BARLOVENTO · AMBOS LLENOS: SOLO A MOTOR / CON POCA GENTE

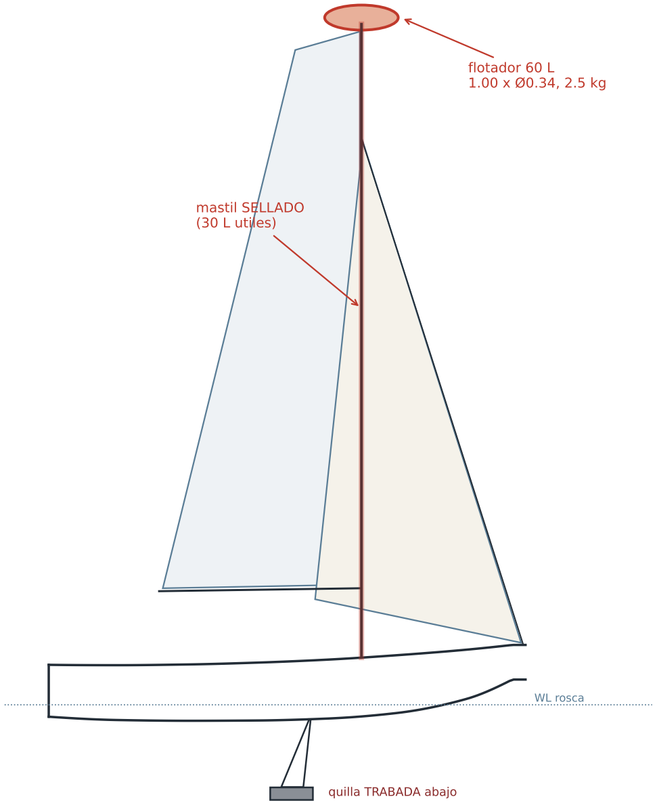
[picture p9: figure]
quilla TRABADA abajo; WL rosca; flotador 60 L 1.00 x Ø0.34, 2.5 kg; mastil SELLADO (30 L utiles)
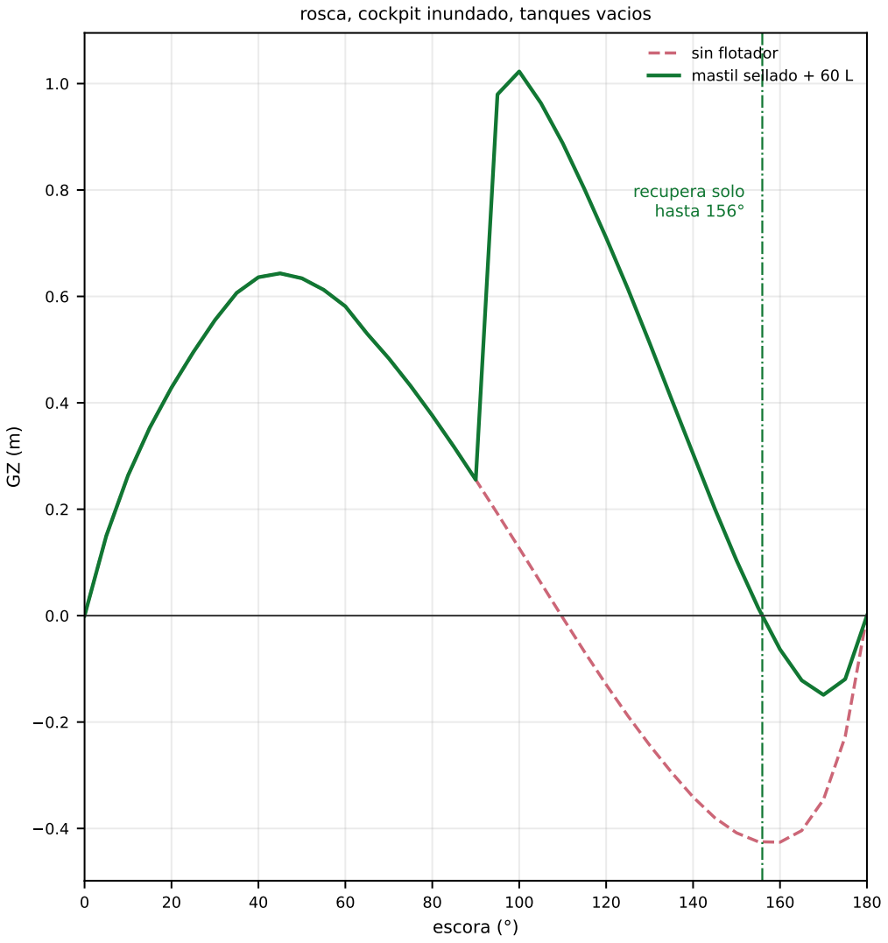
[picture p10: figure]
escora (°); recupera solo hasta 156°; rosca, cockpit inundado, tanques vacios

| sin flotador mastil sellado + 60 L

## L8 · Auto-adrizado: flotador de tope, mastil sellado y condicion de diseno

### FLOTADOR DE TOPE

Elipsoide PE rotomoldeado
1.00 x 0.34 m = 60 L, ~2.5 kg carenado proa-popa (menos
windage que una bola).
Soporte: placa 6082-T6 en el tope, 4x M6 A4; desmontable para regata/remolque bajo.

MASTIL SELLADO
Espuma de cierre en pie, tope y cajeras de roldana; drizas externas o en conducto. 30 L utiles que tambien cuentan.

TRABA DE QUILLA (ver L4)
Obligatoria navegando: la
curva verde supone la quilla abajo Y trabada a 120° de
escora.

### COMO FUNCIONA (calc/autoadrizante.py -- el flotador SI entra a la curva GZ)

El volumen sellado en el tope es flotabilidad como cualquier otra: al sumergirse el aparejo (escora ~75°+) desplaza agua al final de una palanca de 9.5 m, exactamente en el rango donde la curva del casco desnudo se hace negativa. Resultado (rosca, inundado, tanques vacios): recuperacion autonoma desde cualquier escora hasta 156° (casco desnudo: 110°); la energia que sostiene la tortuga cae de 2493 J a 291 J, detras de una barrera de 2636 J. 60 L en el tope = el momento adrizante de ~270 kg de plomo en el bulbo, por 2.5 kg.

### PLACA JUNTO A LA CAJA DE QUILLA (grabar):

### AUTO-ADRIZANTE SOLO CON: QUILLA ABAJO Y TRABADA · TANQUES VACIOS

QUILLA ARRIBA = SOLO BOTADURA / PLAYA · LASTRE DE AGUA: VER PLACA L7 (rendimiento, nunca seguridad)

Cinchas de piso y liston de pie (notes.txt 46-47): se mantienen como respaldo y para la condicion quilla-arriba.

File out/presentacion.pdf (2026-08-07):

# Velero abierto en HDPE

## 6.48 m - 6 plazas - quilla retractil - electrico

Basado en el RS Aira 22 y el Flow 19 - Resumen de proyecto para presentacion

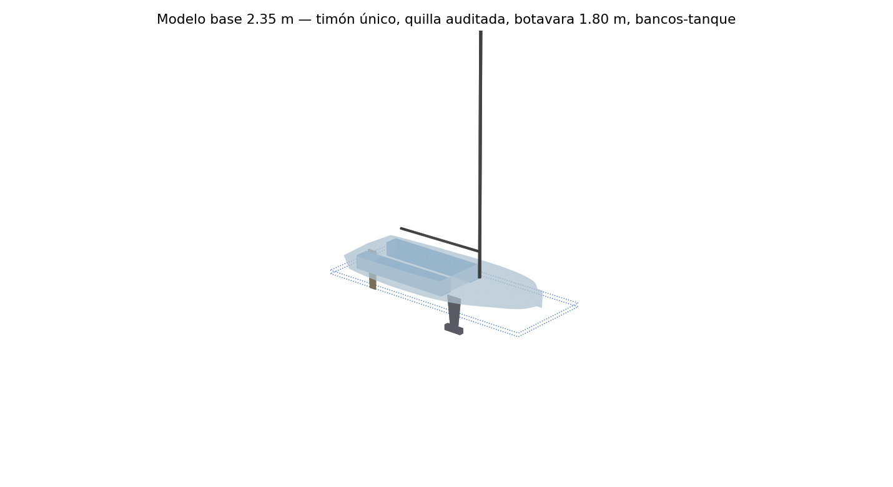
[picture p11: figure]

6 de agosto de 2026 - documento generado desde el modelo de calculo

Documento de ingenieria preliminar. Las cifras provienen del modelo parametrico del proyecto (hidrostatica, estabilidad, escantillonado, pesos y costos); no sustituye el proyecto firmado por ingeniero naval ni la aprobacion de la autoridad maritima.

Velero abierto en HDPE 6.48 m - Resumen de proyecto | 6 de agosto de 2026

# 1. Resumen ejecutivo

Velero abierto de 6.48 m en polietileno de alta densidad (HDPE), cockpit autoachicable de 6 plazas, quilla retractil pivotante, timon unico abatible, auxiliar electrico y 500 L de lastre de agua alojados dentro de los bancos del cockpit. El diseno cumple 30 de las 33 lineas de requisitos del cliente (notes.txt); las 3 restantes estan resueltas como decisiones documentadas, no como omisiones.
Eslora / manga / calado | 6.48 m / 2.35 m / 0.30 m quilla arriba - 1.29 m abajo
Desplazamiento | 750 kg rosca - 1730 kg plena carga (6 tripulantes + 500 L)
Lastre | 213 kg plomo (28.4%) + 500 L agua en bancos-tanque
Superficie velica | 22.0 m2 (mayor 14 + foque enrollable 8), SA/D 15.5
Estructura | HDPE rotomoldeado doble piel 2x5 mm / 50 mm - 9.5 kg/m2
Cumplimiento dimensional | 0 violaciones del sobre LOA/BEA/DIS/SQM/BAL/CBD
Cockpit autoachicable | si: +56 mm de francobordo de piso a plena carga
Auto-adrizado desde 180° | NO en 2.35 m de manga - decision pendiente (seccion 6)
Costo Chile (prototipo soldado) | USD 45-96 mil (medio 64) IVA incluido
Auditoria de constructibilidad | 15/15 verificaciones fisicas PASS (calc/audit.py + out/audit.txt)

### Los tres hallazgos que ordenan el proyecto

- El HDPE no cuesta peso: la doble piel rotomoldeada (346 kg) empata el casco GRP implicito del Aira (358 kg). Lo que compra el lastre es el motor electrico (+58 kg). La piel simple NO es viable (23 mm, 710 kg).
- El sobre de requisitos es la ficha del RS Aira 22 casi textual; ya codifica estructura GRP y sin motor electrico. Por eso el lastre queda en 213 kg contra los 250 del Aira.
- El auto-adrizado verdadero es un problema de manga, no de lastre ni de cockpit abierto: sellar el cockpit mueve el AVS ~1°; 1000 kg de plomo llegan a 149°, no a 180°. Lo unico que funciona es angostar el casco.

# 2. Correcciones pedidas por el cliente - verificadas

Pedido | Estado | Donde
Un timon, no dos | APLICADO | Timon unico central abatible, pala mas profunda (0.85 m); 3DM, especificacion, pesos, costos
Quilla retractil | APLICADO | Quilla pivotante = retractil: 1.28 m abajo / 0.30 m arriba; traba de posicion
Tanques = asientos | APLICADO | Bancos-tanque sellados piso->asiento (0.385->0.80 m); reserva de flotabilidad
Lastre agua 500 L | APLICADO | 2 x 244 L (488 L, dentro del tope); llenado por cuchara, vaciado por bomba de aire
Normativa AR + CL | APLICADO | Ordenanza PNA 1-18 y Circulares DIRECTEMAR A-41/014 + O-71/010 (seccion 8)
Animacion auto-adrizado | APLICADO | out/selfrighting.gif - fisica real sobre las curvas GZ del modelo (seccion 6)

Consecuencias absorbidas y recalculadas: el timon unico devuelve 9 kg a la quilla (204 -> 213 kg); los tanques a la altura del banco invierten el efecto del lastre de agua sobre el vuelco (llenarlos ahora cuesta ~6° de AVS en vez de ganar 4°); y el umbral de auto-adrizado subio a ~452 kg de quilla en 1.80 m de manga. Todo el paquete (calculos, planos, 3DM, documentos) esta regenerado con estos numeros.

# 3. Casco y disposicion

Casco de codaste duro (dos paneles por banda): es la forma que piden los dos procesos de HDPE viables - el rotomoldeo necesita desmolde limpio y la chapa soldada necesita paneles desarrollables. Manga llevada a popa para el cockpit de 6 plazas y espejo semiabierto; entrada fina en proa.

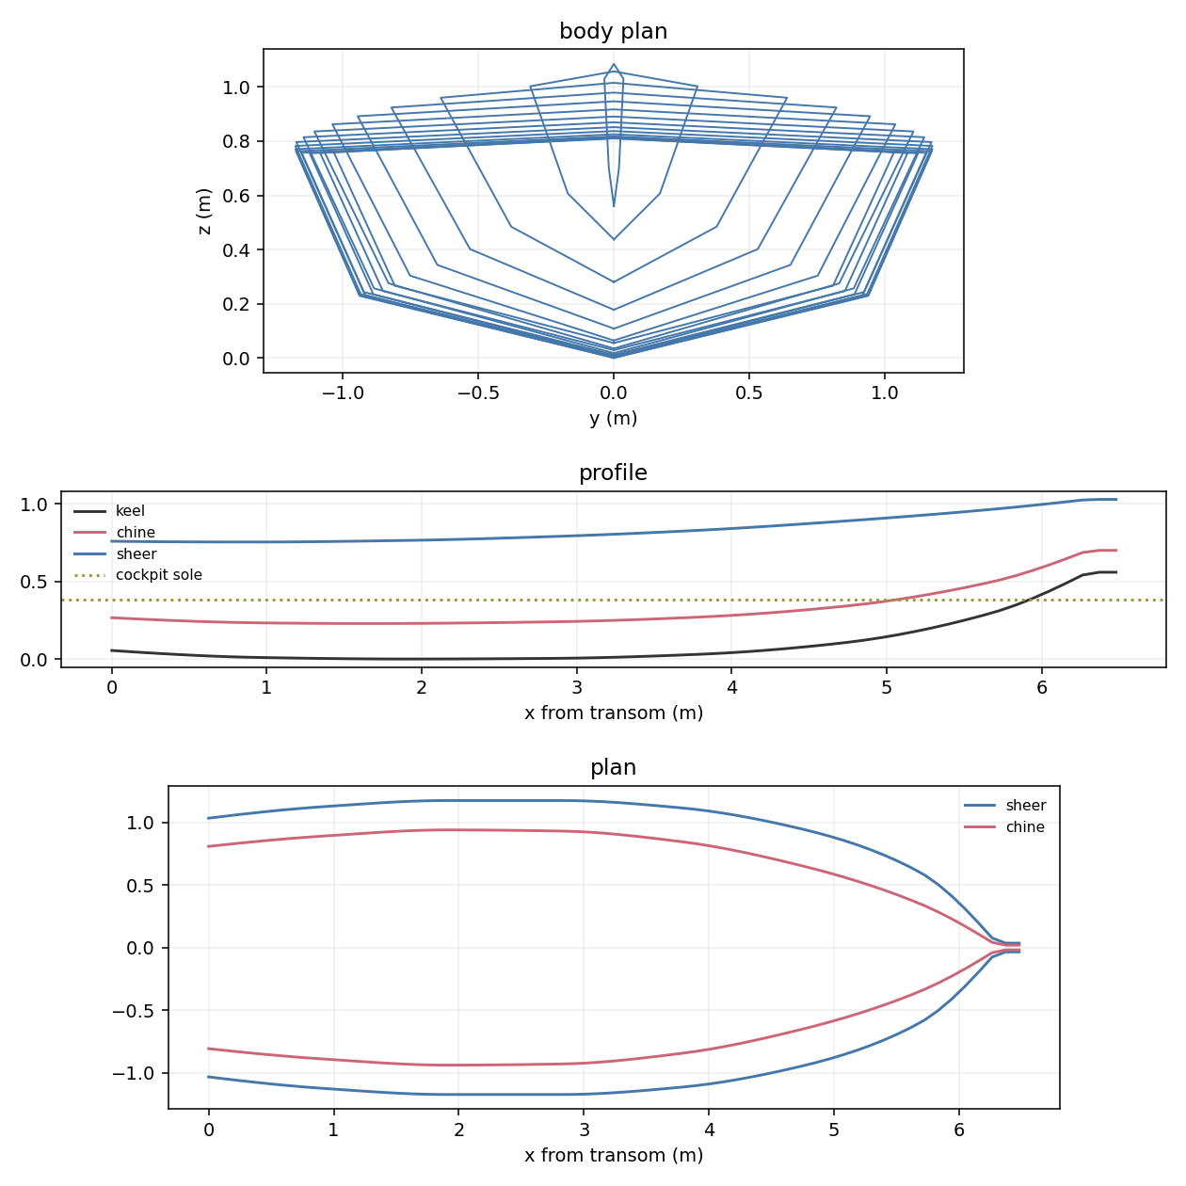
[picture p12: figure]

Plano de lineas: secciones, perfil y planta

Cockpit | 3.20 x 1.72 m, piso a 0.385 m, autoachicable al espejo
Bancos-tanque | 0.42 m de ancho, asiento a 0.80 m; pasillo central 0.88 m
Cubierta proa | plana para tomar sol; cuddy con doble tambucho y estante de tela
Timon | unico, central, abatible, colgado del espejo, cana corta
Quilla | pivotante-retractil en x=3.30 m, bulbo de plomo, aparejo 4:1

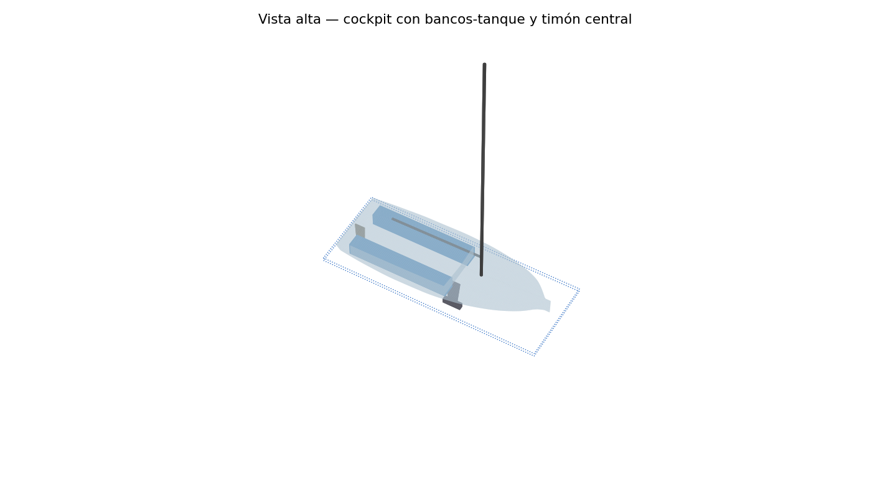
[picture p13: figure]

Vista alta del modelo 3DM: bancos-tanque (azul) y timon central

# 3b. Diseno: color y estilo

En HDPE el color va en la resina (se decide al moldear, no se pinta) y es pasante: los rayones no se notan. Regla tecnica: cubierta, bancos y piso siempre CLAROS (el PE oscuro al sol toma 20-30 °C mas -> fluencia y dilatacion); los costados pueden ser oscuros; el negro/carbono es el PE mas longevo al UV. Cuatro paletas propuestas y los elementos de estilo (defensa PE soldada, nombre en bajorrelieve con inlay, franja de flotacion, antideslizante moldeado, pads EVA en bancos) en docs/09.

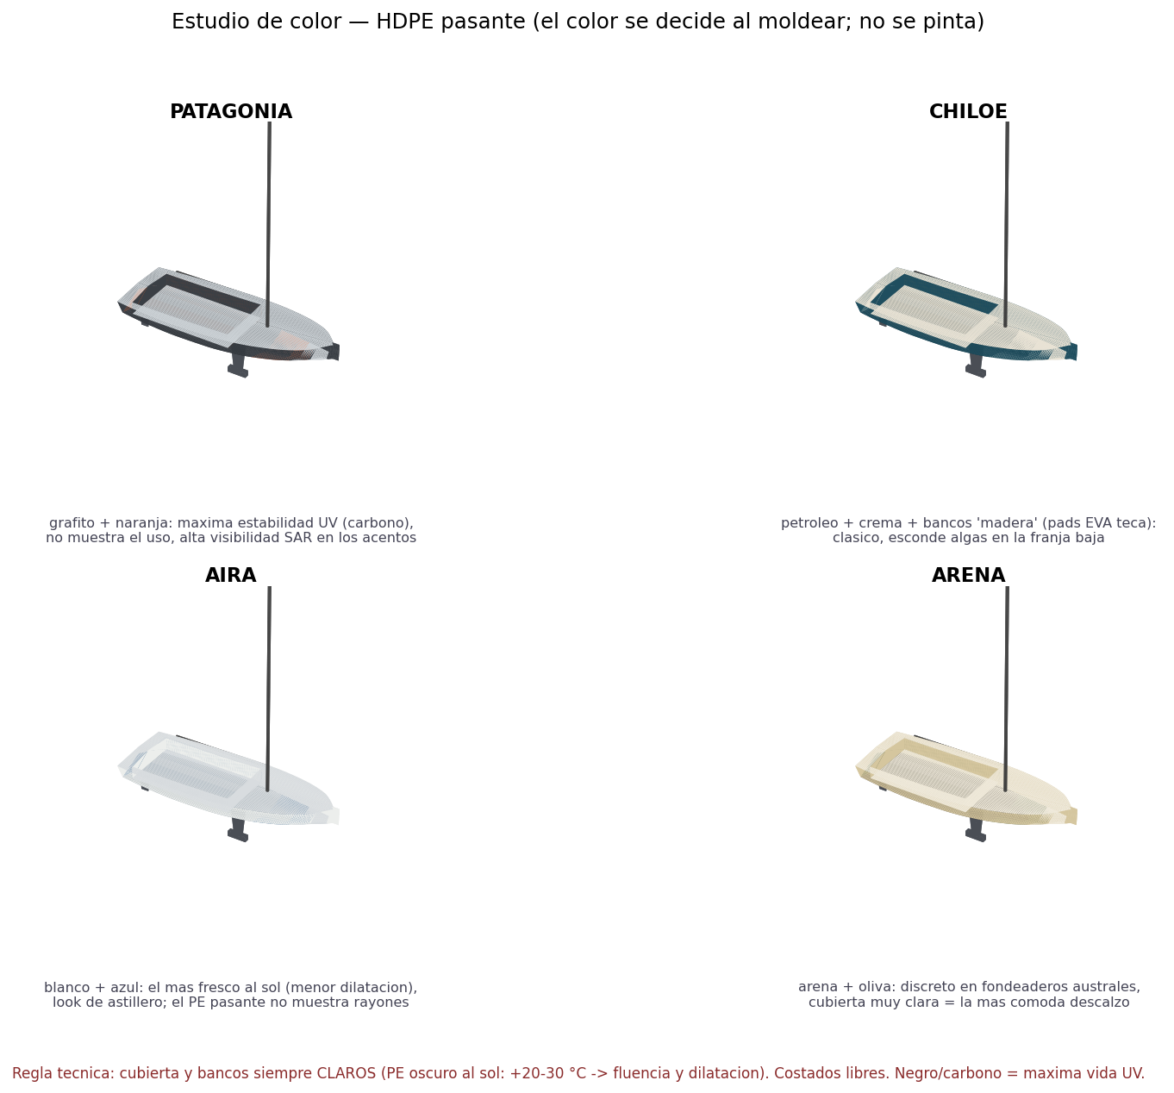
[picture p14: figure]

Cuatro paletas sobre el modelo 3D

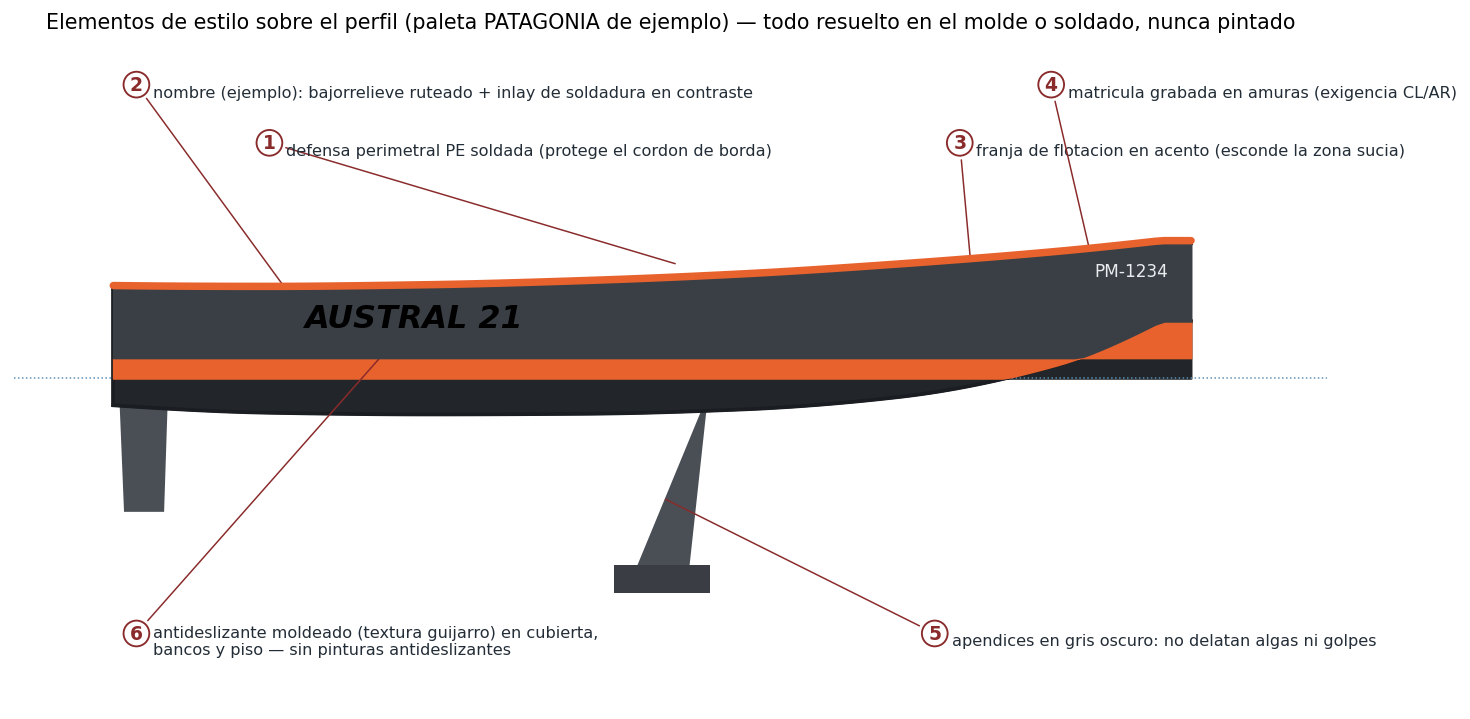
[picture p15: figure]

Elementos de estilo - todo resuelto en el molde o soldado, nunca pintado

# 3c. El bote en el agua

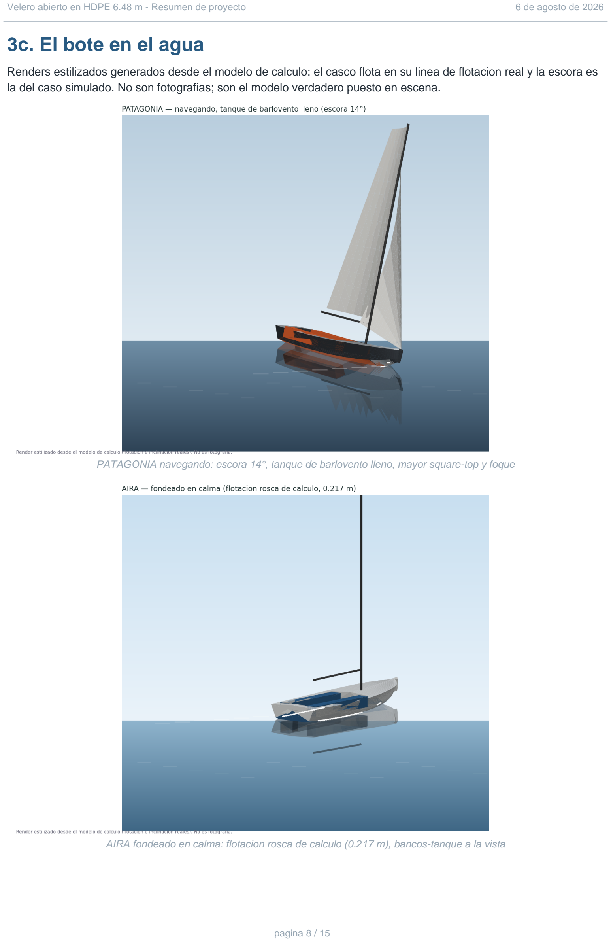
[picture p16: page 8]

Renders estilizados generados desde el modelo de calculo: el casco flota en su linea de flotacion real y la escora es la del caso simulado. No son fotografias; son el modelo verdadero puesto en escena.

PATAGONIA navegando: escora 14°, tanque de barlovento lleno, mayor square-top y foque

AIRA fondeado en calma: flotacion rosca de calculo (0.217 m), bancos-tanque a la vista

# 4. Estructura HDPE

El resultado central: en HDPE manda la rigidez, no la resistencia. Con el modulo derrateado por fluencia (250 MPa, no los 1100 de corto plazo), una piel simple necesitaria 23 mm y pesaria 710 kg: inviable. La respuesta es la doble piel rotomoldeada - dos pieles de 5 mm separadas 50 mm con uniones kiss-off - que rinde como 42 mm solidos con 9.5 kg/m2.
Panel | Presion | Requerido | Provisto | Margen
Fondo | 27.1 kPa | 23.0 mm | 42.2 mm | 1.8x
Costado | 21.4 kPa | 21.2 mm | 42.2 mm | 2.0x
Cubierta | 7.5 kPa | 17.2 mm | 42.2 mm | 2.5x
Piso cockpit | 7.5 kPa | 13.5 mm | 42.2 mm | 3.1x

Prototipo en chapa PE500 soldada: 12 mm sobre refuerzos omega cada 200 mm (+40 kg). Los paneles desarrollan planos desde el espejo hasta x=4.1 m; la proa se termoforma o se resuelve en tracas.

### La regla que gobierna cada union

Nada se pega al HDPE. Toda union es soldadura PE-PE o bulon con placa de respaldo de aluminio y tubos de compresion; el PE fluye bajo carga sostenida y dilata 10 veces mas que el aluminio (agujeros ovalados en tramos largos). Los puntos duros (pie de mastil, cadenotes, escota, eje de quilla) terminan en un esqueleto de aluminio 6082-T6, nunca en el plastico.

### Pesos

Item | kg
Casco + cubierta HDPE (doble piel) | 346
Caja y herrajes de quilla | 22
Timon + cana (unico) | 15
Mastil + botavara + jarcia | 32
Velas + enrollador + lazy bag | 16
Herrajes cubierta + aparejos 2:1 | 19
Motor electrico + bateria 3 kWh | 58
Capota + carpa + fondeo + seguridad | 29
Quilla (plomo, el remanente) | 213
ROSCA (con lastre) | 750

# 5. Estabilidad y porte de vela

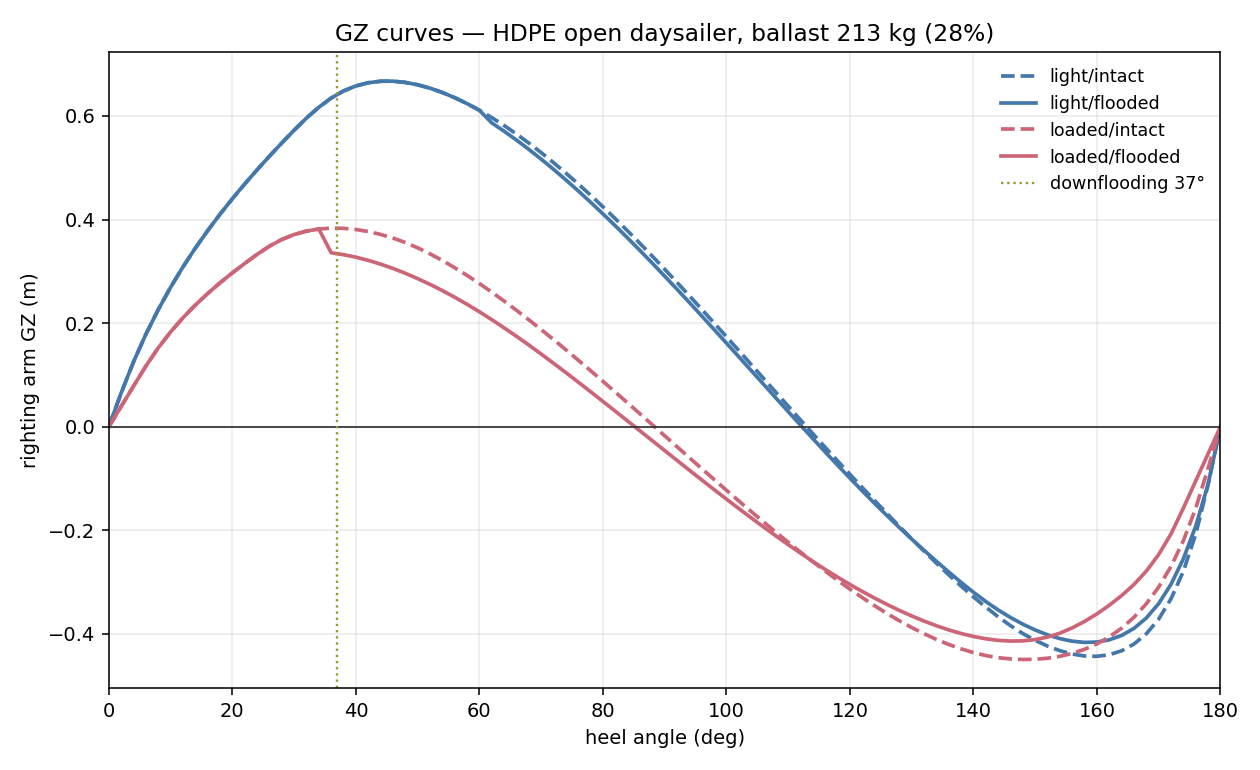
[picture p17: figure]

Curvas GZ 0-180°, intactas e inundadas, rosca y plena carga

Condicion | GZmax | AVS | Auto-adriza
Rosca, cockpit inundado | 0.667 m @ 46° | 112° | no
Plena carga (6 trip + 500 L), inundado | 0.38 m @ 34° | 85° | no
- Cockpit autoachicable verificado: piso +168 mm sobre flotacion en rosca, +56 mm a plena carga (1730 kg). Es el numero mas justo del barco: tolerancia de construccion +10/-0 mm.
- Porte de vela: 17° de escora con 20 nudos reales (12° con tanque de barlovento lleno); momento adrizante maximo a 28 nudos; primer rizo ~18 nudos.
- Angulo de inundacion 37° a plena carga - el numero para entrenar a la tripulacion en un barco abierto.

### Regla operativa del lastre de agua (para placa junto a las valvulas)

- Tripulacion completa (5-6): tanques VACIOS - la tripulacion es el lastre; con tanques llenos el AVS cargado cae a ~85°.
- 1-3 tripulantes: tanque de BARLOVENTO lleno = ~2 tripulantes en la borda (250 kg a 0.65 m).
- Llenado simetrico: solo a motor o en mar de popa con poca gente - a la altura del banco, llenar ambos cuesta ~6° de AVS.

# 6. Auto-adrizado: la decision pendiente

El requisito 'auto-adrizante' desde 180° NO se cumple con 2.35 m de manga, y no es un problema de esfuerzo sino de fisica: la misma estabilidad de forma que sostiene 6 personas y 22 m2 de vela hace al casco estable boca abajo. Sellar el cockpit mueve el AVS ~1°. Una tonelada de plomo llega a 149°.

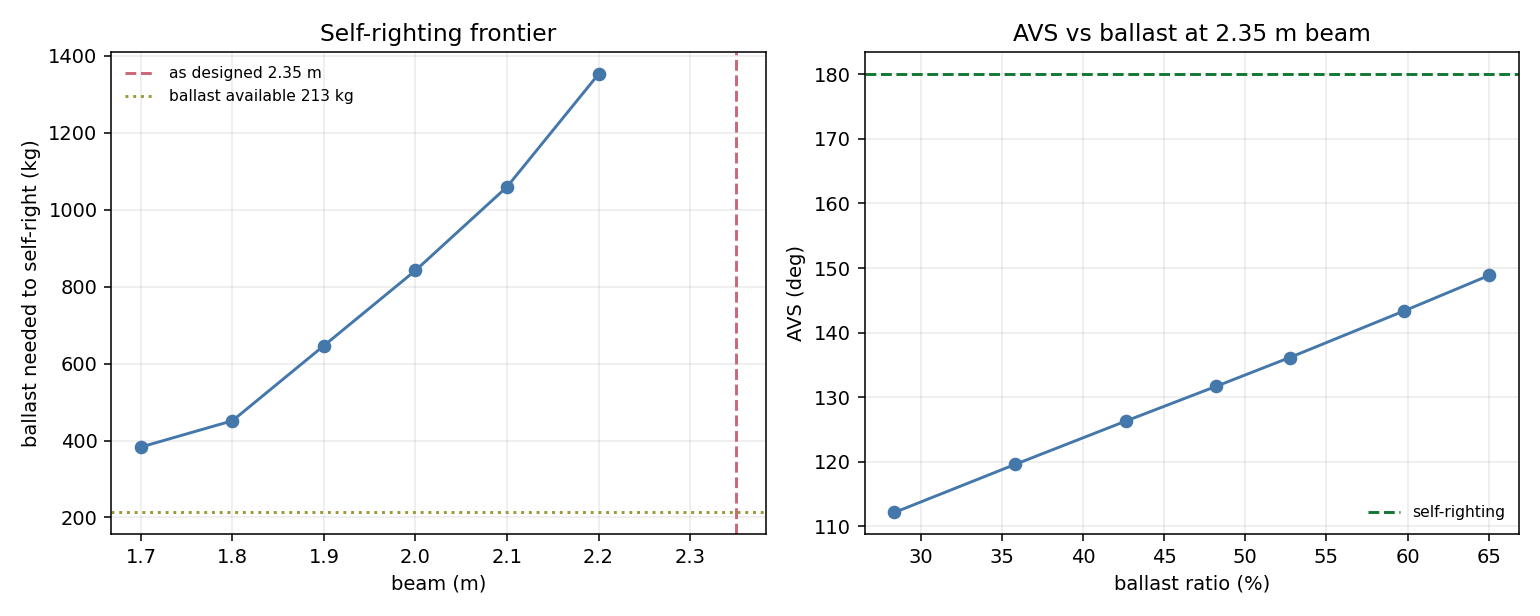
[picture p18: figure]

Frontera: lastre minimo para auto-adrizar segun manga - y AVS vs lastre a 2.35 m

Manga | Lastre necesario | Desplazamiento
1.75 m | 417 kg | ~954 kg
1.80 m | 452 kg | ~988 kg
2.00 m | 842 kg | ~1379 kg
2.35 m (diseno) | no alcanzable < 1400 kg | -

### Las dos resoluciones honestas

- OPCION A - flotador de tope de mastil (45-60 L, ~2.5 kg): hace inalcanzable los 180°; el barco queda a ~112° y la tripulacion lo adriza con las cinchas de piso ya previstas. No cambia nada mas del proyecto. No es auto-adrizado literal: es anti-tortuga + adrizado por tripulacion.
- OPCION B - variante angosta 1.80 m con 452 kg de quilla (~988 kg): auto-adriza de verdad. Pierde las 6 plazas en linea (4 comodas), supera el tope de 750 kg y el remolque necesita frenos. Ya esta modelada y exportada (hull_selfrighting.stl / boat_selfrighting.3dm).

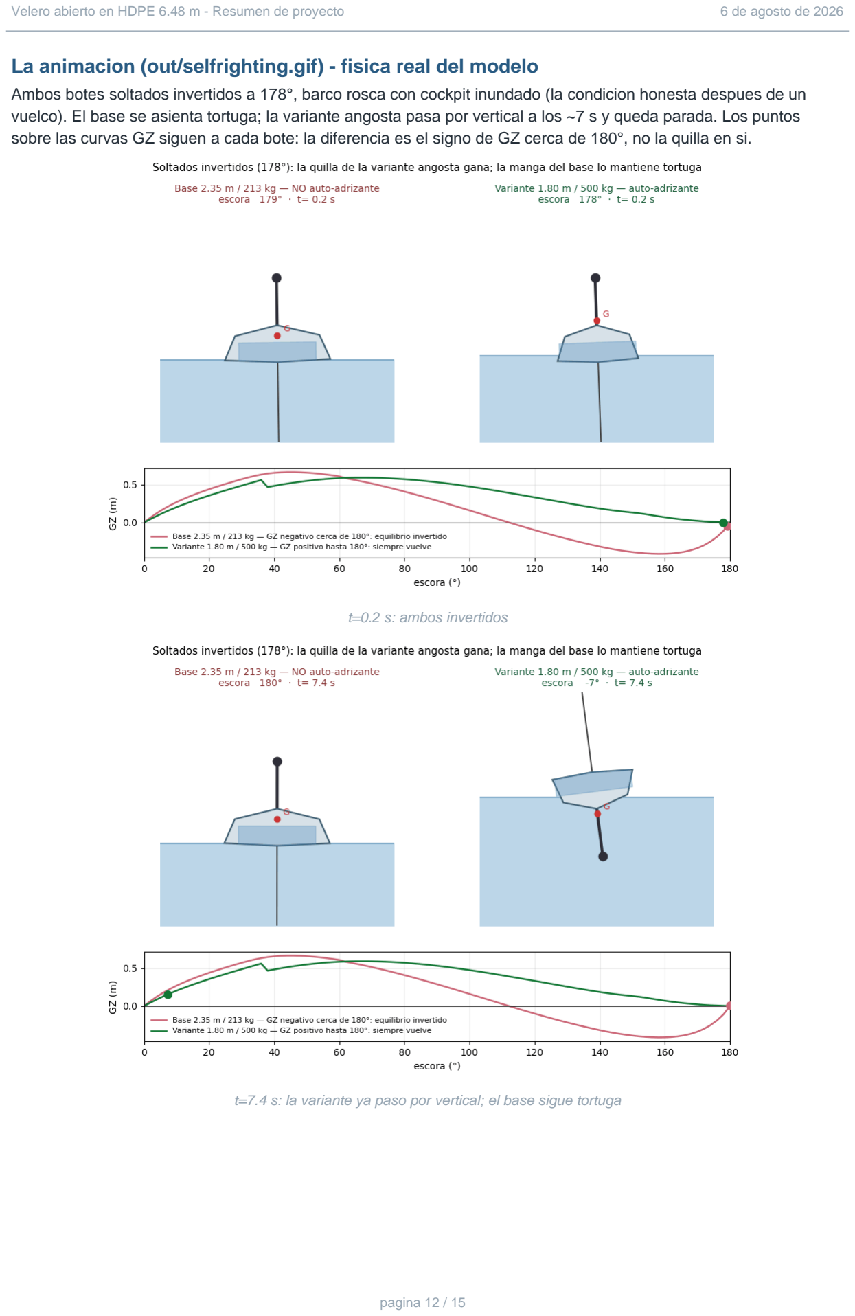
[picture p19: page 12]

### La animacion (out/selfrighting.gif) - fisica real del modelo

Ambos botes soltados invertidos a 178°, barco rosca con cockpit inundado (la condicion honesta despues de un vuelco). El base se asienta tortuga; la variante angosta pasa por vertical a los ~7 s y queda parada. Los puntos sobre las curvas GZ siguen a cada bote: la diferencia es el signo de GZ cerca de 180°, no la quilla en si.

t=0.2 s: ambos invertidos

t=7.4 s: la variante ya paso por vertical; el base sigue tortuga

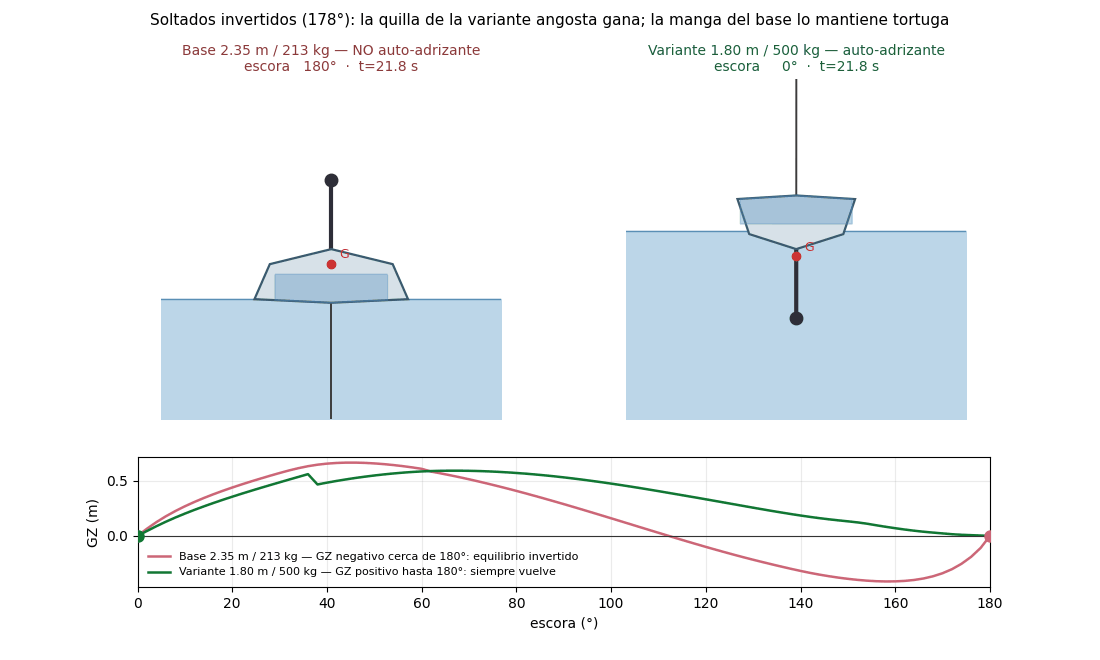
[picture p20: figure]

t=22 s: estado final - la manga decide

# 7. Normativa: Argentina y Chile

Los dos sistemas regulan distinto y eso ordena el plan: Argentina regula la CONSTRUCCION (proyecto firmado y aprobado antes de cortar material); Chile regula el BARCO TERMINADO (inspeccion local, prueba de balance, equipamiento). Disenar el papeleo para Argentina y el equipamiento para Chile satisface ambos.

| Argentina (PNA) | Chile (DIRECTEMAR)
Antes de construir | Proyecto + Encomienda de profesional CPIN; aprobacion PNA (Ord. 1-18) | Barco abierto <12 m: croquis + 4 fotos ante la SCLINM (O-71/010)
Estabilidad | Memoria de calculo en el proyecto | Prueba de periodo de balance en el agua
Registro | REJU / REY | Capitania de Puerto + Cert. de Navegabilidad (6 anos)
Patron | Timonel de Yate a Vela | Licencia deportiva segun clase
Equipamiento | Anexo A Ord. 1-18 por zona; ancla 7 kg + 12 mm + cadena 6 mm | Anexo A Circ. A-41/014 por clase (bahia / costera 12-60 MN)

### Dos puntos de friccion detectados en la norma

- Chile exige lastre 'de instalacion permanente' (A-41/014 II.K.1): los tanques soldados integrales son defendibles, pero conviene acordarlo POR ESCRITO con la Capitania antes de construir. Plan B: tanques sellados permanentes de 120 kg.
- La mayor no enrollable debe rizar >=40% del gratil (A-41/014 II.M): resuelto con 2 fajas de rizos en la especificacion.
- ISO 12215-5 no tiene via para PE rotomoldeado: la certificacion ISO es equivalencia + ensayos, no un checklist. AR/CL no exigen ISO.

# 8. Costos de construccion en Chile

Bandas de planificacion 2026 (BAJO / MEDIO / ALTO), IVA 19% incluido, importados +15% flete y 0% arancel (TLC). Modelo parametrico en calc/costs.py: reemplazar las bandas por cotizaciones reales y recalcular.
| Bajo | Medio | Alto
RUTA A - chapa PE500 soldada, unidad unica
Materiales + componentes | 29,800 | 41,400 | 57,800
Mano de obra (650-1000 h) | 10,800 | 17,100 | 29,800
Contingencia 10% | 4,100 | 5,900 | 8,800
TOTAL USD | 44,700 | 64,400 | 96,300
TOTAL CLP (millones) | 42 | 61 | 91
RUTA B - rotomoldeo, por barco en serie de 20
TOTAL USD | 43,800 | 63,600 | 94,900
- El casco no es el costo: la chapa PE es ~5% del total. El bloque mayor es el tren electrico (~USD 9,900, 24% de materiales), despues aparejo + velas.
- En serie de 20, rotomoldeo empata a la chapa soldada (la amortizacion del molde cancela el ahorro de mano de obra). Para UN barco: chapa soldada; un molde de USD 60-130 mil no se carga a una unidad.
- Chile es buen lugar para soldar PE: la industria salmonera ya forma soldadores y hay astilleros de HDPE en Puerto Montt/Chiloe. La cotizacion mas valiosa: casco a precio fijo de un fabricante acuicola.
No incluye: remolque, amarra, honorarios de ingeniero naval en Argentina (USD 2,500-6,000, solo para matricula argentina), certificado de vela, flete.

# 9. Proximos pasos

# | Accion | Quien

1 | Decidir auto-adrizado: Opcion A (flotador) u Opcion B (variante 1.80 m) - antes de cualquier molde | Cliente
2 | Consulta escrita a la Capitania (CL) por el lastre de agua 'permanente' | Cliente / proyecto
3 | Cotizar casco soldado con 2 fabricantes PE (Santiago y Puerto Montt) con la especificacion seccion
2-3

Proyecto

4 | Cotizar tren electrico: dealer chileno vs importacion directa | Proyecto
5 | Si va matricula argentina: contratar ingeniero naval (CPIN) y presentar proyecto a PNA | Cliente
6 | Construir prototipo -> prueba de balance (valida el modelo y el certificado chileno) | Astillero

Paquete tecnico completo en el repositorio: requisitos, especificacion de construccion con dimensiones y materiales, estudio de auto-adrizado, normativa con fuentes primarias, matriz de cumplimiento (30/33) y modelo de costos - mas planos de formas, STL, 3DM por capas y la animacion.

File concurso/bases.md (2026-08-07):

# Concurso de diseño naval con IA — velero abierto HDPE 6.48 m

**Para estudiantes y jóvenes profesionales de Ingeniería Naval (UTN)**

## 1. La idea

Diseñar con IA no es pedirle un barco a un chat: es usar modelos de lenguaje
para construir, criticar y explotar **modelos de cálculo reales** — hidrostática,
escantillonado, pesos, estabilidad — más rápido y más a fondo de lo que un
equipo llega solo. Este concurso pone esa práctica sobre un proyecto real y
verificable: el velero abierto de 6.48 m en HDPE de este repositorio, con su
cadena de cálculo paramétrica abierta (`calc/`, `geom/`).

Cada equipo recibe el mismo problema de ingeniería real (los **desafíos**), el
mismo modelo paramétrico y la misma vara de medir (el **evaluador
automático**). Lo que se compara no es quién dibuja mejor: es quién explora
mejor el espacio de diseño — y la IA es la pala.

## 2. Qué entrega un equipo

1. **Un diseño**: un archivo JSON con los parámetros del barco
   (`plantilla_diseno.json` — manga, calados, piso, bancos, aparejo, lastre,
   paquete de tope de mástil…). El evaluador lo convierte en un barco real:
   corre la hidrostática y las curvas GZ 0–180° con cockpit inundado, verifica
   el sobre dimensional y puntúa.
2. **Una bitácora de IA** (obligatoria): qué herramientas usaron, los prompts
   clave, qué propuso la IA, qué estaba mal y cómo lo detectaron, qué
   verificaron a mano. Se califica el *criterio*, no la cantidad de prompts.
   La regla de oro del concurso: **la IA propone, el ingeniero verifica**.
3. **Una memoria corta** (máx. 4 páginas): la lógica del diseño y las
   decisiones frente a los desafíos.

## 3. Cómo se participa (flujo GitHub)

1. Fork del repositorio.
2. Copiar `concurso/plantilla_diseno.json` a
   `concurso/entregas/<nombre-equipo>.json` y completarlo.
3. Probar localmente: `python3 -m concurso.evaluar concurso/entregas/<equipo>.json`
   — imprime el puntaje automático y genera la tarjeta de resultados.
4. Pull request con el JSON + bitácora (`entregas/<equipo>-bitacora.md`) +
   memoria (PDF). El PR es la inscripción.
5. La organización corre el evaluador oficial, publica la tarjeta en el
   leaderboard de la página del concurso, y el jurado califica lo no
   automatizable.

## 4. Puntaje

**Automático (hasta 100 pts)** — lo calcula `concurso/evaluar.py`, igual para todos:

| Rubro | Pts | Cómo se mide |
|---|---|---|
| Sobre dimensional | 20 | LOA<6.50, BEA<2.50, DIS<750, SQM<22, BAL<500 L, CBD<1.30 — se descuenta por violación |
| Auto-adrizado | 35 | límite de recuperación autónoma (rosca, cockpit inundado, tanques vacíos): 110°→0 pts, 180°→35 pts |
| Seguridad operativa | 20 | francobordo de piso a plena carga (autoachique) y ángulo de inundación |
| Porte de vela | 15 | SA/D a plena carga en banda sana (15–18) |
| Presupuesto de lastre | 10 | relación de lastre alcanzada dentro del tope de 750 kg |

**Jurado (hasta 40 pts)**:

| Rubro | Pts |
|---|---|
| Bitácora de IA: criterio, verificación, honestidad sobre errores de la IA | 20 |
| Innovación real y constructibilidad (¿se puede soldar/moldear?) | 12 |
| Claridad de la memoria | 8 |

Descalifican: parámetros fuera de rango físico (los valida el evaluador),
bitácora ausente o fabricada, plagio entre equipos.

## 5. El rol del Líder de IA

Figura nueva y central del concurso — dos capas:

- **Humano (Director/a de IA del concurso)**: mantiene el evaluador y el
  leaderboard, dicta el taller inicial de "IA para ingeniería" (cómo hacer que
  un LLM escriba y critique código de cálculo, cómo detectar alucinaciones
  numéricas, cómo documentar la bitácora), atiende consultas técnicas y audita
  las bitácoras.
- **Agente de IA oficial (el "Copiloto del concurso")**: un asistente
  disponible para todos los equipos por igual, cargado con este repositorio,
  que responde sobre el modelo de cálculo, explica resultados del evaluador y
  hace pre-chequeo de entregas. Que exista un copiloto común nivela la cancha:
  ningún equipo pierde por no tener acceso a herramientas.

Dentro de cada equipo se sugiere el mismo rol en miniatura: un integrante como
*líder de IA* responsable de la bitácora y de la verificación.

## 6. Cronograma sugerido (8 semanas)

| Semana | Hito |
|---|---|
| 1 | Lanzamiento + taller "IA para ingeniería naval" (obligatorio, 3 h) |
| 2–3 | Exploración: los equipos corren el modelo, entregas de práctica ilimitadas |
| 4 | Entrega intermedia (checkpoint en el leaderboard, no puntúa) |
| 5–6 | Iteración con feedback del evaluador |
| 7 | Entrega final (PR congelado) |
| 8 | Evaluación del jurado + jornada final presencial: defensa de 10 min por equipo |

## 7. Logística mínima a definir con la facultad

- Aval del departamento de Ingeniería Naval (UTN) y 2–3 jurados (un docente
  de arquitectura naval, un constructor de PE/astillero, el Director de IA).
- Equipos de 2–4; categoría estudiantes y categoría jóvenes profesionales.
- Premios (a definir): pasantía en astillero, licencias de software, y el
  compromiso de que **el diseño ganador se incorpora al proyecto real** como
  variante documentada — ese es el premio que importa.
- Acceso: el repo es público; solo hace falta una cuenta de GitHub y Python.

## 8. Por qué esto enseña IA de verdad

El evaluador es implacable: una curva GZ no se convence con un buen prompt.
Los equipos van a descubrir rápido que la IA acelera muchísimo — para leer el
código de cálculo, proponer variantes, escribir scripts de barrido, explicar
por qué un diseño falla — y que también inventa números con total confianza.
Aprender a usar lo primero y atrapar lo segundo **es** la competencia que la
profesión todavía no tiene, y es exactamente lo que este concurso mide.

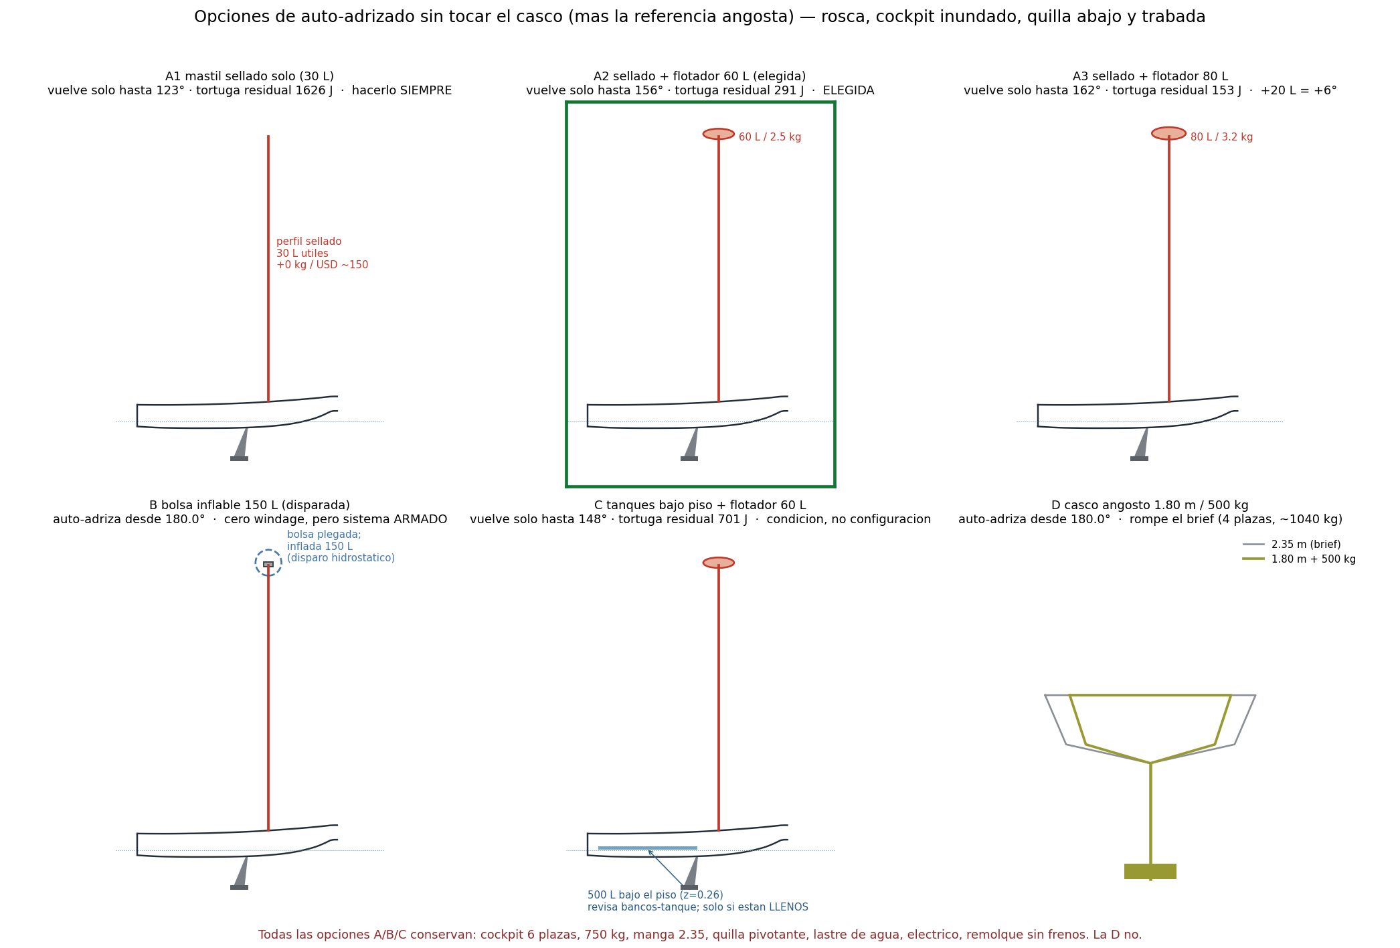
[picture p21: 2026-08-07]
autoadrizante/opciones_board.png

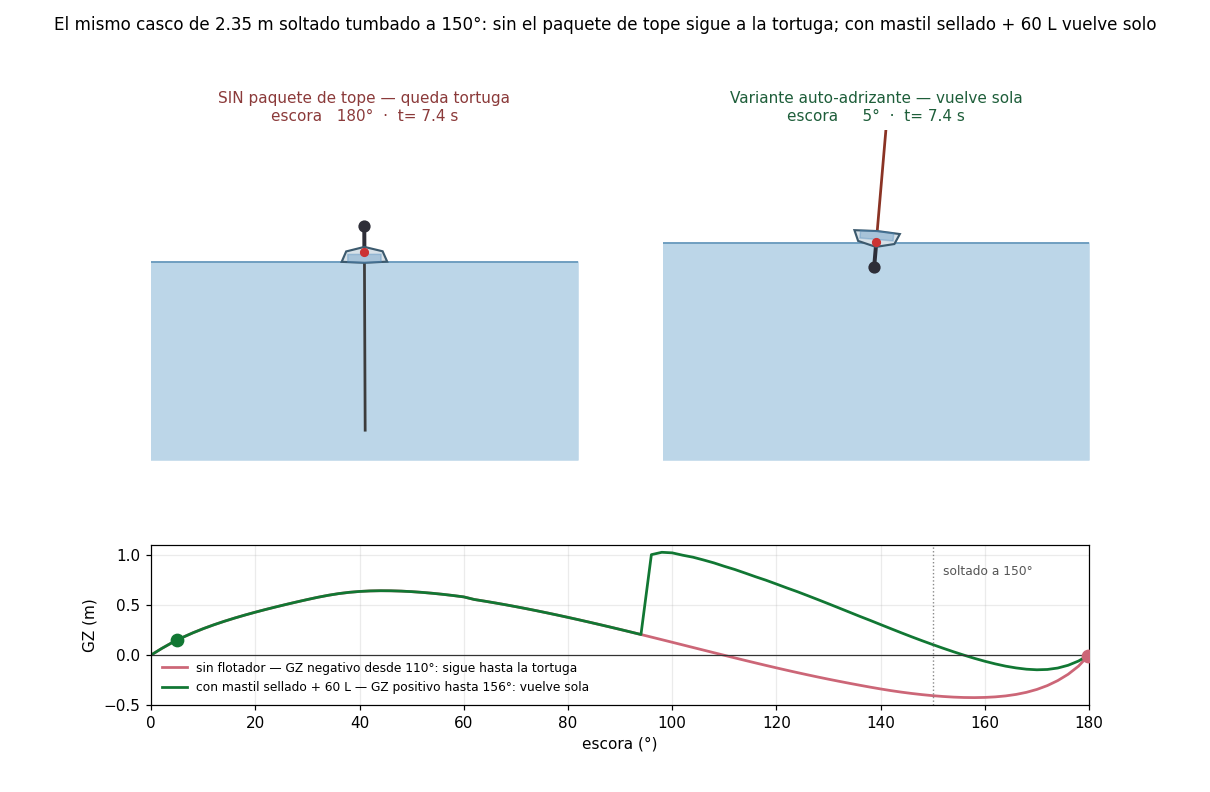
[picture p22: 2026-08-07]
autoadrizante/anim_medio.png

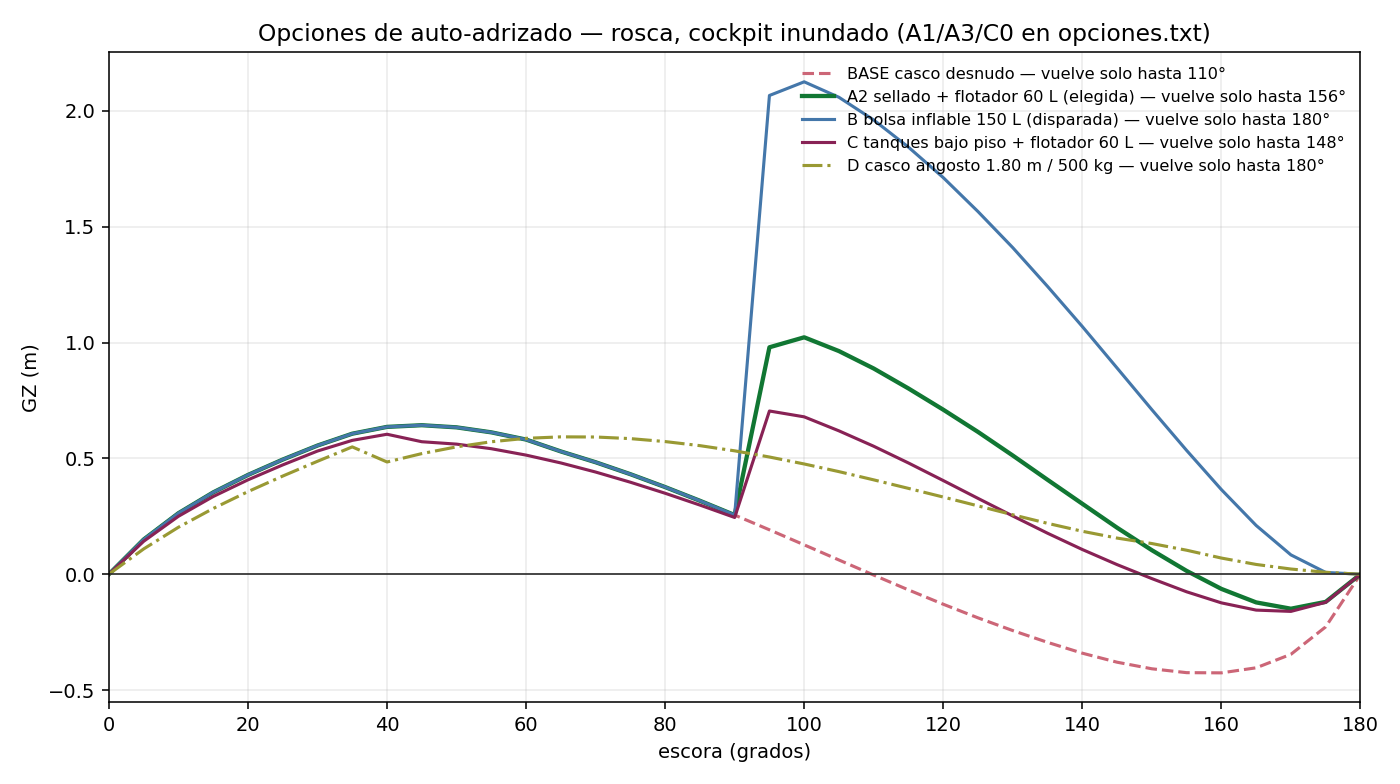
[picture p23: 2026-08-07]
autoadrizante/opciones_gz.png

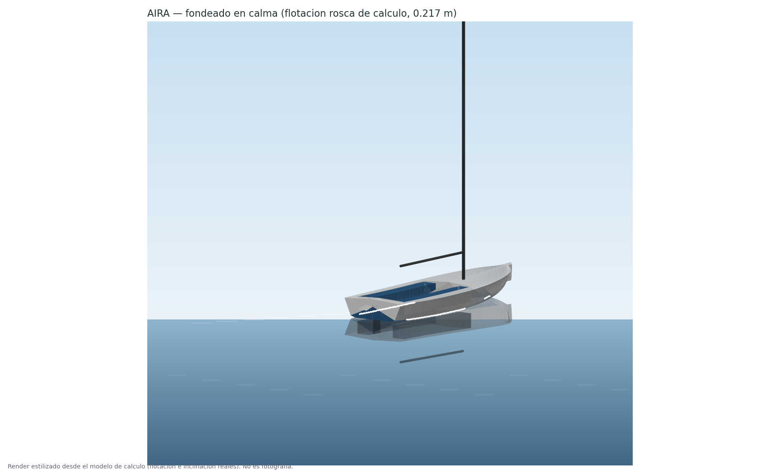
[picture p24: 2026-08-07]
out/foto_aira_fondeado.png

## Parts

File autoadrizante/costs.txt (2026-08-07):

================================================================================================
COST ANALYSIS -- BUILDING IN CHILE
Assumptions: 950 CLP/USD | IVA 19% included in all totals | imports +15% freight, 0% duty (FTA)
Bands are LOW / MID / HIGH planning prices, 2026. [QUOTE] lines need real quotes.
================================================================================================

--- SHELL -- ROUTE A: WELDED PE500 SHEET (one-off / prototype) ---------------------------------
item                                                   qty unit       LOW      MID      HIGH  basis
PE500 sheet (net 420 kg + 15% waste)                   483 kg       2,012    2,586     3,449  [QUOTE]  Plastigen / Polymerland / Plastisan / Siplas -- quote cut-to-size
HDPE welding rod 4-5 mm                                 16 kg         152      190       248  [QUOTE]
PE consumables (tips, tacks, test coupons)               1 lot        178      298       476  [EST]
SUBTOTAL (USD, IVA incl.)                                           2,343    3,074     4,172

--- SHELL -- ROUTE B: ROTOMOULDED (series of 20) -----------------------------------------------
item                                                   qty unit       LOW      MID      HIGH  basis
Rotomoulding powder (380 kg incl. yield)               380 kg         724      859     1,040  [QUOTE]  UV8 rotograde, compounded colour
Moulding service, 2 shots (hull + deck)                  1 lot      2,142    3,570     5,950  [QUOTE]  machine >= 4 m swing -- capability to be confirmed in Chile
Tooling amortisation (1/20 of tool)                      1 boat     3,570    5,355     7,735  [EST]  series production only; a one-off carries the whole tool
PE welding (bench walls, keel case, details)             8 kg          76       95       124  [QUOTE]
SUBTOTAL (USD, IVA incl.)                                           6,512    9,879    14,849

--- COMMON: BALLAST, FOILS, STRUCTURE, RIG, SAILS, SYSTEMS, SAFETY -----------------------------
item                                                   qty unit       LOW      MID      HIGH  basis
Lead, cast bulb (delivered, cast)                      170 kg         566      688       850  [QUOTE]  LME ~2.1 + casting; Chilean foundry
Keel fin S355 25 mm, profiled + HDG                     40 kg         190      262       357  [QUOTE]  plasma-cut + galvanised, local maestranza
Keel pivot pin 316 + acetal bushes + cheeks              1 lot        416      654     1,012  [EST]
Rudder blade PE500 20 mm + alloy stock (single)          1 lot        357      536       774  [EST]
Gudgeons + tiller fittings                               1 lot        274      438       684  [EST]
6082-T6 plate & sections (spine, beams, backers)        38 kg         317      384       497  [QUOTE]
Machining/fabrication of alloy parts                     1 lot        714    1,190     1,904  [QUOTE]
Mast section 8.6 m + fittings                            1 lot      2,737    3,695     4,927  [QUOTE]  dinghy/sportboat extrusion; Selden/AG+ class
Boom + gooseneck + outhaul                               1 lot        821    1,163     1,642  [QUOTE]
Standing rigging 5 mm 1x19 + terminals                   1 lot        411      616       890  [MKT]
Running rigging (2:1 systems, halyards)                  1 lot        479      684     1,026  [MKT]
Deck hardware: blocks, clutches, cleats, padeyes         1 lot      1,916    2,600     3,558  [MKT]  no winches -- this is the saving that pays for it
Square-top main 14 m2, 2 reefs                           1 lot      2,463    3,148     4,105  [QUOTE]  Chilean loft (e.g. local) or imported
Furling jib 8 m2                                         1 lot      1,232    1,642     2,190  [QUOTE]
Furler (small-boat, e.g. CDI FF2 class)                  1 lot        958    1,300     1,779  [MKT]
Lazy bag + cover                                         1 lot        298      416       595  [QUOTE]  local lonería
Electric outboard ~4 kW (Navy/Cruise class)              1 lot      5,748    7,527     9,579  [MKT]  incl. throttle/cables
LiFePO4 48 V ~3 kWh + BMS + box                          1 lot      1,505    2,326     3,558  [MKT]
DC-DC 48>12, panel, wiring, nav lights (LED)             1 lot        684    1,026     1,505  [MKT]
Bilge: electric pump + manual pump + bailer              1 lot        342      520       753  [MKT]  manual pump required (PNA 1-18 4.6)
Scoops, ball valves, cross-connect, vents, hoses         1 lot        616      890     1,300  [EST]
12 V diaphragm air pump (tank empty)                     1 lot        205      301       479  [MKT]
Sight tubes, placards, sole strap anchors                1 lot        143      214       333  [EST]
A4 (316) fasteners, oversize washers, comp. tubes        1 lot        616      890     1,300  [MKT]
Acrylic bow hatches x2, PE-framed                        1 lot        411      616       890  [EST]
Butyl tape, gaskets, sealants (PE-compatible)            1 lot        205      301       479  [MKT]
Spray hood + cockpit tent (lonería)                      1 lot      1,071    1,547     2,261  [QUOTE]
Cuddy fabric shelf, nets, misc canvas                    1 lot        178      298       476  [QUOTE]
Safety equipment per A-41/014 (bahia..12 MN)             1 lot        821    1,232     1,916  [MKT]  lifejackets ISO 12402, flares, extinguisher, anchor 7 kg + line
SUBTOTAL (USD, IVA incl.)                                          26,694   37,104    51,619

--- REGULATORY (Chile) -------------------------------------------------------------------------
item                                                   qty unit       LOW      MID      HIGH  basis
Matricula, roll test day, cert fees, photos              1 lot        298      536       952  [EST]  Capitania de Puerto
SUBTOTAL (USD, IVA incl.)                                             298      536       952

================================================================================================
TOTALS (USD, IVA included)
================================================================================================

ROUTE A -- welded sheet one-off
  Materials + components:      29,334      40,713       56,743
  Labour (650-1000 h @ 14-25 USD/h):    10,829      17,136       29,750
  Contingency 10%:             4,016       5,785        8,649
  TOTAL USD:                  44,179      63,634       95,142
  TOTAL CLP (millions):         42.0        60.5         90.4

ROUTE B -- rotomoulded, per boat in a series of 20
  Materials + components:      33,503      47,518       67,419
  Labour (350-600 h @ 14-25 USD/h):     5,831       9,639       17,850
  Contingency 10%:             3,933       5,716        8,527
  TOTAL USD:                  43,268      62,873       93,796
  TOTAL CLP (millions):         41.1        59.7         89.1

Route B one-off (whole tool on one boat): add USD 60,000-130,000 tooling.

NOT included: trailer, mooring, Argentine project/engineering fees
(ingeniero naval -- quote in Argentina, typ. USD 2,500-6,000 for a boat
this size incl. Encomienda), sail-number cert, delivery.

==============================================================================
DELTA VARIANTE AUTO-ADRIZANTE  (sobre cualquiera de las rutas de arriba)
==============================================================================
  Flotador de tope 60 L (PE rotomoldeado o soplado, 1.00 x 0.34) USD 120-350
  Soporte de tope 6082-T6 + 4x M6 A4                             USD 40-90
  Sellado del perfil (espuma pie/tope/cajeras, mano de obra)     USD 80-200
  Conducto de drizas / drizas externas (delta vs interno)        USD 0-120
  Traba de quilla reforzada (ya prevista: sin delta)             USD 0
  ------------------------------------------------------------------------
  TOTAL DELTA                                                    USD 240-760
  ~0.5 % del costo medio del barco (USD 64,400). El paquete se paga con
  2.5 kg de plomo de quilla, que ademas ahorra ~USD 10 de plomo.

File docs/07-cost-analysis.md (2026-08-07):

# Cost analysis — building in Chile

Generated by `calc/costs.py` (full line-item tables in `out/costs.txt`). Every
unit price is a **low/mid/high planning band**, tagged `[QUOTE]` where a real
Chilean quote is needed, `[MKT]` where international pricing is stable, `[EST]`
for engineering estimates. **These are 2026 planning numbers, not offers** —
the script exists so the client's real quotes replace the bands and the totals
recompute consistently.

Assumptions: 950 CLP/USD · IVA 19% included in every figure · imports +15%
freight, 0% duty (Chile's FTAs with EU/US/China cover essentially all the
marine gear).

---

## 1. Headline totals (USD, IVA included)

| | Low | **Mid** | High |
|---|---|---|---|
| **Route A — welded PE500 sheet, one-off** | | | |
| Materials + components | 29,800 | **41,400** | 57,800 |
| Labour (650–1000 h @ 14–25 USD/h) | 10,800 | **17,100** | 29,800 |
| Contingency 10% | 4,100 | **5,900** | 8,800 |
| **Total** | **44,700** | **64,400** | **96,300** |
| Total CLP | 42 M | **61 M** | 91 M |
| | | | |
| **Route B — rotomoulded, per boat in a series of 20** | | | |
| Materials + components (incl. tooling share) | 33,900 | **48,200** | 68,400 |
| Labour (350–600 h) | 5,800 | **9,600** | 17,900 |
| Contingency 10% | 4,000 | **5,800** | 8,600 |
| **Total** | **43,800** | **63,600** | **94,900** |

**Not included:** trailer, mooring/storage, Argentine engineering fees
(ingeniero naval + Encomienda, typ. USD 2,500–6,000 — needed only for the
Argentine registration path), sail-number certificate, delivery.

## 2. What the numbers actually say

**The hull is not where the money is.** Welded PE shell material is ~USD 3,100
mid — about 5% of the boat. The cost lives in the systems: the **electric
drivetrain (motor + battery ≈ USD 9,900 mid, 24% of materials)** is the single
largest block, then rig + sails (≈ 11,600), then hardware and systems. This is
the cost-side confirmation of what the weight budget already showed: the
electric auxiliary, not the HDPE, is the expensive decision.

**At a series of 20, rotomoulding ≈ welded sheet in cost per boat** (63.6 vs
64.4 k mid): the tooling amortisation (~5,400/boat) is almost exactly cancelled
by the labour saving (~7,500/boat). Rotomoulding wins on consistency, finish,
the true double-skin structure (lighter shell → the full 213 kg keel), and
per-unit cost keeps falling beyond 20 units. **For one boat it is not a
contest: welded sheet, USD ~64 k mid, vs carrying a 60–130 k tool on a single
hull.**

**The realistic programme is Route A first anyway** — the prototype validates
the roll test, the water-ballast conversation with the Capitanía, and the
operating rules, before anyone cuts a tool.

## 3. Chile-specific notes

- **Sheet suppliers to quote** (all active, from the supplier search):
  [Plastigen](https://plastigen.cl/productos/polimeros-de-ingenieria/comprar-polietileno/),
  [Polymerland](https://www.polymerland.cl/contenido.php?id_articulo=238),
  [Plastisan](https://plastisan.cl/211-placa-hdpe),
  [Siplas](https://www.siplas.cl/placashdpe),
  [Servicios Plastisur (Puerto Montt)](http://www.serviciosplastisur.cl/productos.php?prod=3) —
  the last one matters if the build is in the south. None publish per-kg
  prices; the 3.5–6.0 USD/kg band is the expected quote range for PE500
  cut-to-size.
- **Rotomoulding capability is the open question for Route B.** Chilean
  rotomoulders routinely make large water tanks, but a 6.5 m boat half needs
  ≥4 m of machine swing per piece — confirm capability (or price importing
  moulded shells from Brazil/Argentina) before taking Route B seriously.
- **PE welding labour**: HDPE extrusion welding is an established trade in
  Chile via the aquaculture industry (salmon-farm pontoons and pipework, HDPE
  boats already exist in Puerto Montt/Chiloé) — this is genuinely favourable
  for Route A, both for rates and for finding welders certified to DVS-style
  practice.
- **Lead**: cast locally (fishing-weight and battery foundries); LME basis
  ~2.1 USD/kg plus casting.
- **Electric outboard pricing** is US-list based
  ([ePropulsion Navy series](https://www.epropulsion.com/products/electric-outboards/navy-evo);
  the [Practical Sailor buyer's guide](https://www.practical-sailor.com/systems-propulsion/electrical/buyers-guide-14-electric-outboard-options-from-2-5-to-9-9-horsepower/)
  is a good option survey) — Chilean dealer margins can add 10–25% over the
  modelled freight; a direct-import quote is worth it.

## 4. Sensitivity (mid-case, Route A)

| Driver | Swing | Effect on total |
|---|---|---|
| Shop labour rate 14→25 USD/h | +11 USD/h | +USD 10,500 |
| Electric drive → best-price import | −20% | −USD 2,000 |
| CLP devalues 950→1100 | −14% CLP | CLP total +16 M (USD total ~flat; imported share is USD-linked) |
| PE500 quote 4.5→3.5 USD/kg | −22% | −USD 570 (small — see §2) |
| Drop battery to 1.5 kWh | −USD 900 | and returns ~16 kg to the keel |

Labour rate dominates. Getting a fixed-price shell quote from an aquaculture
HDPE fabricator is the single most valuable quote in the whole exercise.

## 5. How to use this

1. Send `docs/04-build-spec.md` §2–3 + the offsets to two PE fabricators
   (one in the Santiago area, one in Puerto Montt) for a shell quote.
2. Get the drivetrain quoted both from a Chilean dealer and as direct import.
3. Replace the `[QUOTE]` bands in `calc/costs.py` with the numbers, re-run
   `python3 -m calc.costs`, and the totals update with tax and freight applied
   consistently.

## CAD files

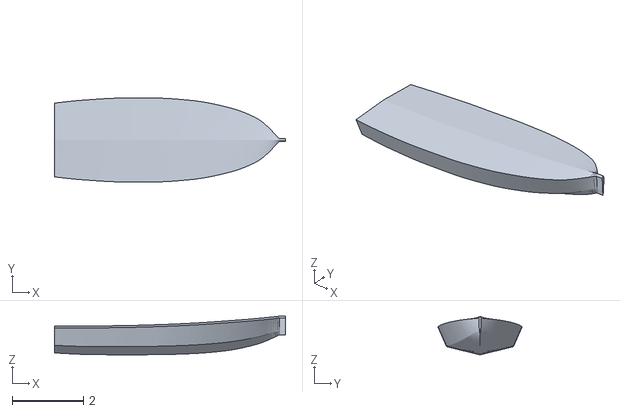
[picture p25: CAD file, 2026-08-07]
autoadrizante/hull_autoadrizante.stl
6.48 x 2.35 x 1.09

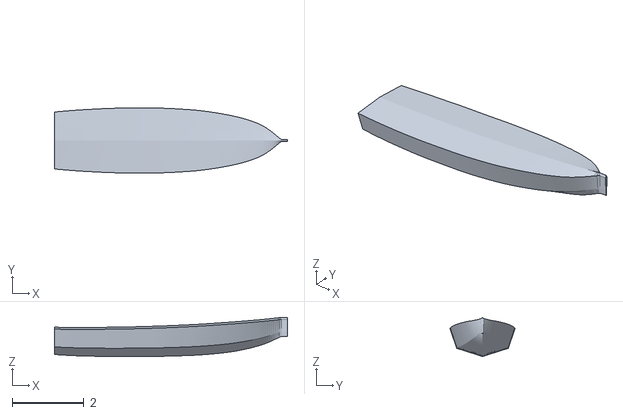
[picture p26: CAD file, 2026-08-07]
out/hull_selfrighting.stl
6.48 x 1.80 x 1.09

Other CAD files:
out/hull_baseline.stl
autoadrizante/boat_autoadrizante.3dm
out/boat_baseline.3dm
out/boat_selfrighting.3dm

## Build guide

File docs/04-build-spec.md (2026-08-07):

# Build specification

Everything needed to build the boat: dimensions, materials with grades,
scantlings, construction details and a bill of materials. Geometry comes from
`out/offsets_baseline.txt` (table of offsets, 121 stations) and
`out/boat_baseline.3dm` (dimensioned 3D model, metres). Where a number is an
engineering assumption it is tagged; nothing here is decorative.

**Read first:** §9 of `02-design-spec.md` — this boat as specified does **not**
meet the true self-righting requirement. Building to this spec means accepting
the masthead-float resolution (Option A) or switching to the 1.80 m variant
(`offsets_selfrighting.txt`). Everything below describes the 2.35 m baseline.

---

## 1. Principal dimensions (as-built targets)

| | Value | Tolerance |
|---|---|---|
| LOA | 6.480 m | ±15 mm |
| LWL (light) | 6.30 m | — |
| Beam, sheer | 2.350 m | ±10 mm |
| Beam, chine | 1.880 m | ±10 mm |
| Canoe-body depth (baseline→sheer, min) | 0.755 m | ±8 mm |
| Deck crown above sheer | 0.055 m | — |
| Cockpit (L × W inside walls) | 3.200 × 1.720 m | ±10 mm |
| Cockpit sole above baseline | 0.385 m | +10/−0 mm — governs self-draining |
| Bench seats (top above baseline) | 0.800 m | ±10 mm |
| Bench width | 0.420 m | — |
| Footwell width between benches | 0.880 m | — |
| Draft, keel up / down | 0.30 / 1.29 m | — |
| Light displacement incl. keel | 750 kg | +0/−25 kg |
| Keel (fin + lead), total | 213 kg | ±2 kg, assembly VCG 0.86 m below baseline |

Full hull shape: `out/offsets_baseline.txt` — x from transom, half-breadths and
heights for keel, chine, sheer, crown at 54 mm station spacing. Loft from this
or section the 3DM directly.

## 2. Materials schedule

| Application | Material | Spec |
|---|---|---|
| Hull + deck shell (rotomoulded) | HDPE rotomoulding powder | MFI 3–6 g/10 min, density ≈ 940–950 kg/m³, UV8 stabilised (e.g. Matrix/ExxonMobil rotograde or regional equivalent). Colour compounded-in, not painted — HDPE takes no paint. |
| Hull + deck (welded-sheet prototype alternative) | PE300 (PE-HWU) or PE500 sheet | Extrusion-weldable, UV-stabilised black or through-coloured |
| Welding rod | Same resin family as sheet/moulding | 4–5 mm HDPE rod; hot-gas extrusion welding, DVS 2207-4 practice |
| Keel ballast | Lead, cast | Antimony-hardened (2–4% Sb) for casting; 213 kg |
| Keel fin structure | Steel S355, hot-dip galvanised | Plate 15 mm, chords 0.50/0.30 m, 6 mm root doublers both faces |
| Backing plates, mast spine, transverse beams | Aluminium 6082-T6 | Plate 6–10 mm |
| Keel pivot pin | Stainless 316, Ø25 mm | With PE-friendly polymer bushes (acetal) |
| Fasteners, all external | Stainless A4 (316) | M8–M12; **oversized washers ≥3× bolt Ø on every PE face** |
| Standing rigging | 1×19 stainless 316 wire, Ø5 mm | Forestay + 2 shrouds; no backstay by design |
| Running rigging | Polyester double-braid 8–10 mm | 2:1 purchases, no winches |
| Spars | Aluminium 6061-T6 or 6082-T6 extrusion | Mast Ø ~110×2.5 mm section or dinghy-class equivalent, boom 90×2 mm |
| Sails | Dacron 250–300 g/m² | Square-top main 14.0 m² **with 2 reef rows (≥40% luff reduction total — Chilean Circular A-41/014 II.M requires it for a non-furling main)**; furling jib 8.0 m² |
| Trampoline/nets, cuddy shelf | PVC mesh / canvas | `estante tela`, notes line 20 |
| Sealant at fastener penetrations | Butyl tape or MS polymer | Silicone and epoxies do not bond PE — use gaskets and compression, never adhesion |

**The one rule that governs every joint: nothing glues to HDPE.** Every
connection is a weld (PE to PE) or a bolted compression joint with load spread.
PE creeps: any bolt bearing on unreinforced PE will loosen. Every bolted joint
gets an aluminium backing plate on the PE side, torqued to compress a defined
gasket area, with slotted holes where the span exceeds ~0.5 m (PE expands
~200 µm/m per 10 °C — 10× aluminium).

## 3. Shell scantlings

### Production: rotomoulded double skin

| Parameter | Value |
|---|---|
| Skins | 2 × 5.0 mm nominal (−0/+1 mm) |
| Skin gap | 50 mm |
| Kiss-offs (tack-offs) | Ø ~60 mm at 75 mm pitch, both directions, bottom and topsides; 100 mm pitch deck |
| Areal mass | 9.5 kg/m² |
| Shell total (hull + deck + cockpit, 32.6 m²) | ≈ 346 kg incl. reinforcement |

Verification (from `calc/scantlings.py`, ISO 12215-5-form pressures, category C,
creep-derated E = 250 MPa):

| Panel | Design pressure | Required equiv. t | Provided | Margin |
|---|---|---|---|---|
| Bottom | 27.1 kPa | 23.0 mm | 42.2 mm | 1.8× |
| Topsides | 21.4 kPa | 21.2 mm | 42.2 mm | 2.0× |
| Deck | 7.5 kPa | 17.2 mm | 42.2 mm | 2.5× |
| Cockpit sole | 7.5 kPa | 13.5 mm | 42.2 mm | 3.1× |

Face stresses ≤1.5 MPa against 7 MPa allowable. The kiss-off pitch, not global
bending, sizes the skins — do not stretch the pitch past 90 mm on the bottom.

### Prototype: welded PE500 sheet

12 mm single skin on welded top-hat stiffeners (PE, 60×40×8 mm section) at
200 mm pitch, bottom and sides; 10 mm deck on 250 mm pitch. Weight penalty
≈ +40 kg over the rotomoulded shell — take it out of the keel and accept 165 kg
of ballast, or accept 790 kg light. Sheet development: panels are flat-formable
from the transom to x = 4.10 m; forward of that, either strake-split the panels
or thermoform the stem over a simple male plug.

## 4. Structure and hard points

The internal skeleton is aluminium, because rig and keel loads cannot terminate
in creeping plastic.

| Item | Specification |
|---|---|
| Mast spine | 6082-T6 channel 120×60×8 mm, under-deck, spanning stations at x = 3.55 → 5.05 m, through-bolted to 3 PE bulkhead webs (audited: 138 MPa at 11 kN rig compression) |
| Mast step | Cast/machined alloy base on the spine; compression post to keel-case top not required (deck-stepped, loads into spine) |
| Chainplates (×2) | 6082-T6 strap 50×8 mm, outside face; backing plate 300×150×8 mm inside, 6× M10 A4 through both skins with compression tubes so bolts do not crush the double skin |
| Forestay fitting | Stem head alloy weldment, 4× M10 through the (solid at stem) bow moulding |
| Mainsheet anchor | Transverse 6082 beam 80×40×4 box under the sole at x = 1.55 m, bearing on both bench-tank inner walls; single centreline padeye — no traveller by design |
| Keel case | Rotomoulded/welded PE box, wall 12 mm, capped by 8 mm alloy cheek plates each side; pivot pin Ø25 316 at x = 3.30 m, z = 0.05 m |
| Keel bolts / pivot bearing area | Cheek plates through-bolted 8× M12; acetal bushes; grease nipple |
| Rudder gudgeons (×2) | Alloy, through-transom on 150×100×6 backing plates, 4× M8 each |
| Bench-tank walls | Structural: they carry the sole and stiffen the topsides. 8 mm PE inboard wall, welded to sole and hull; tops removable gasketed hatches for inspection |
| Compression tubes | At EVERY bolt through double skin: PE or alloy tube, skin-to-skin, so torque does not crush the sandwich |

## 5. Keel and rudders (foil dimensions)

**Pivoting keel** — NACA 0012-faired plate fin (audited in `calc/audit.py`):

| | |
|---|---|
| Root chord / tip chord | 0.50 / 0.30 m |
| Span below hull (down) | 1.06 m |
| Fin | S355 plate **15 mm** + 6 mm root doublers, profiled, HDG — 50 kg (bending 157 MPa at max RM, SF 2.3 on yield) |
| Ballast | **163 kg lead bulb 0.58 × 0.145 × 0.17 m (14.3 L)** cast around the fin tip, centroid z = −0.99 → **assembly VCG −0.86** |
| Draft, down | 1.294 m to bulb bottom (inside CBD 1.30) |
| Pivot | x = 3.30 m, Ø25 pin; raised draft 0.30 m; case slot ~1.21 × 0.18 m |
| Lift | 4:1 tackle to cockpit; hold-down latch (keel is buoyancy-negative, but a knockdown must not retract it) |

**Rudder (single, centreline)** — NACA 0010, kick-up blade:

| | |
|---|---|
| Chord (mean) | 0.26 m |
| Immersed span | 0.85 m |
| Blade | HDPE-skinned foam or solid PE500 20 mm, alloy stock |
| Position | Transom-hung on centreline, kick-up pivot, short tiller. Transom drain scuppers split either side of the stock. |

## 6. Rig dimensions

| | |
|---|---|
| Mast length / height above deck | 8.60 m, deck-stepped at x = 4.25 m |
| I (foretriangle height) | 7.05 m (hounds at 82% — fractional) |
| J (stem to mast) | 2.20 m |
| P (main luff) | 7.55 m |
| E (main foot) | 2.75 m |
| Boom height above baseline | **1.80 m** — 1.0 m over the bench tops, so a tall seated adult (pan + 0.95 m) clears it. Audited; 1.66 m did not clear. |
| Main | 14.0 m² square-top, 2 reef rows, lazy bag |
| Jib | 8.0 m² on furler |
| Shroud base | Chainplates at x = 4.05 m, y = ±1.10 m; swept spreaders ~20° aft replace the backstay |
| Purchases | Main 2:1, jib sheets 2:1, keel lift 4:1 — no winches |

## 7. Water ballast system (bench-tanks)

| | |
|---|---|
| Tanks | 2, inside the bench seats: x 0.35–3.55 m, y 0.44–0.86 m, sole to 0.62 m fill level (seat top 0.80) |
| Capacity | 250 kg (244 L) each; 488 L total — inside the 500 L cap |
| Fill | Ø38 mm scoop thru-hull per side at the chine, forward-facing, ball valve — fills in ~3 min above 4 kt. No pump load. |
| Vent | Ø25 mm to cockpit wall, goose-necked |
| Empty | 12 V diaphragm air pump (notes line 56) pressurising the tank through the vent line, water forced back out the scoop; plus gravity dump when heeled |
| Cross-connect | Ø51 mm valved transfer line under the sole for tacking the ballast |
| Level | Clear sight tube on each inboard bench wall |

Operating rule (from the stability model): **crew full → tanks empty; crew 1–3 →
windward tank; symmetric fill only for motoring/damping.** One tank to windward
≈ righting moment of two crew.

## 8. Electrical / propulsion

| | |
|---|---|
| Motor | 4 kW electric outboard (e.g. class of Torqeedo Cruise 4.0 / ePropulsion Navy 6), transom bracket on backing plate |
| Battery | 3.0 kWh LiFePO₄, 48 V, in a ventilated sealed box under the sole at x ≈ 2.0 m (z = 0.22) — strapped per Chilean Circular A-41/014 II.K (heavy items secured) |
| Nav lights | Per COLREG/RIPA; ≥10 W or LED equivalent (A-41/014 II.J) — masthead tricolour + steaming |
| Bilge | 12 V electric pump in the footwell sump **plus manual pump** (PNA 1-18 §4.6 requires the manual pump for coastal zones) + bucket/bailer |
| Panel | 6-way, main isolator, 48→12 V DC-DC for lights/pumps/VHF |

## 9. Weights as specified

| Item | kg |
|---|---|
| Shell (rotomoulded, incl. reinforcement) | 346 |
| Keel case + pivot hardware | 22 |
| Keel fin + lead | 213 total — see note |
| Rudder + tiller (single) | 15 |
| Spars + standing rigging | 32 |
| Sails + furler + lazy bag | 16 |
| Deck hardware + purchases | 19 |
| Motor + battery | 58 |
| Spray hood + cockpit tent | 11 |
| Anchor, lines, safety | 18 |
| **Light ship** | **750** |

Note: the 213 kg "keel ballast" line in the budget is total keel mass allowance:
**163 kg lead + 50 kg fin steel** (audited — a 25 mm fin would have weighed
~100 kg and made the assembly VCG unreachable).
VCG of the combination held at −0.86 m by bulb placement.

## 10. Build sequence (rotomoulded route)

1. CNC-cut station moulds from the offsets → fabricate the two-piece shell tool
   (hull half, deck/cockpit half) in welded steel sheet.
2. Rotomould hull and deck halves; kiss-offs formed by tool bosses. Wall
   thickness audit: ultrasonic, 9 points/m², reject <4.5 mm.
3. Weld hull/deck flange (extrusion weld inside + outside beads at the sheer).
4. Weld in bench-tank inboard walls, keel case, sole (if not moulded in).
5. Fit aluminium skeleton: mast spine, mainsheet beam, chainplate backers —
   all on compression tubes and butyl gaskets.
6. Hang keel (pivot + cheek plates), rudders, deck hardware.
7. **Leak-test the bench tanks** (air, 0.15 bar, soap) — they are both ballast
   tanks and the reserve buoyancy; a leaking tank is a safety failure, not a
   nuisance.
8. Step rig, tune (swept spreaders pre-bend ~20 mm).
9. **Inclining/roll-period test** — required for the Chilean paperwork (O-71/010
   Anexo B) and it validates the stability model: measured light ship must be
   750 ±25 kg, VCG 0.24 ±0.03 m. If it isn't, the model and the operating
   rules get re-run before the boat carries six people.

## 11. What this spec does not include

- **Class-A fair NURBS surfaces for the production tool.** The offsets and 3DM
  are dimensionally complete but mesh-faceted; the toolmaker lofts fair splines
  through the offsets (standard practice) or a naval CAD pass does it first.
- **FEA of the four hard points.** The sizes above are engineering estimates
  with generous load spreading; a professional check of chainplate, mast spine,
  keel case and gudgeons is cheap insurance and — in Argentina — will be done
  anyway by the *ingeniero naval* who signs the project (see `05-regulatory.md`).
- **Certified stability documentation.** The GZ curves here are calculation,
  not certification; the roll test in §10.9 is where paper meets water.

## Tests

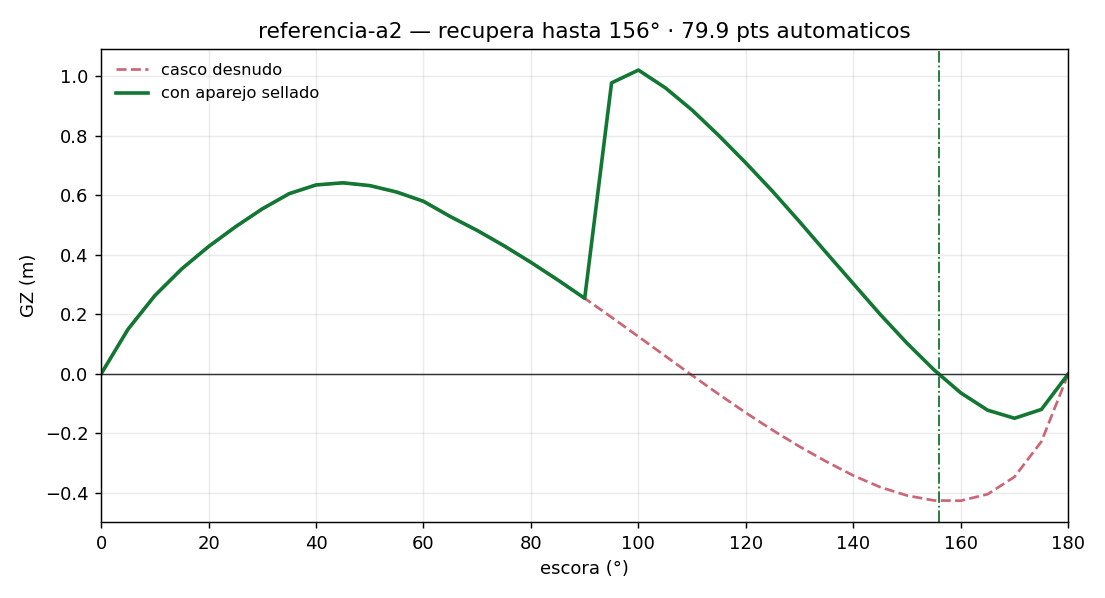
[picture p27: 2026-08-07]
concurso/resultados/referencia-a2/gz.png

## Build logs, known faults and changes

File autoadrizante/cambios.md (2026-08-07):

# Cambios: baseline → variante auto-adrizante

Registro de todo lo que cambia entre el proyecto base (`out/`, `docs/`) y esta
variante, y de lo que expresamente NO cambia. Decision del cliente
(2026-08-07): mantener el daysailer abierto y liviano, y resolver el
auto-adrizado con volumen sellado en altura en vez de plomo — la "Opcion A"
de `docs/03`, ahora **modelada en la fisica** en lugar de estimada.

## 1. Hardware (3 items nuevos, 1 reclasificado)

| # | Cambio | Baseline | Variante |
|---|---|---|---|
| 1 | **Flotador de tope** | no tiene | elipsoide PE 60 L, 1.00 × 0.34 m, carenado proa-popa, 2.5 kg con soporte (placa 6082-T6, 4× M6 A4), desmontable |
| 2 | **Mastil sellado** | perfil abierto | espuma de cierre en pie, tope y cajeras; drizas externas o en conducto; 30 L utiles que tambien cuentan como flotabilidad |
| 3 | **Traba de quilla** | prevista en L4 como buena practica | **item de seguridad primaria**: la afirmacion auto-adrizante supone la quilla abajo Y trabada a 120°+ de escora |
| 4 | Cinchas de piso + liston (notes 46-47) | mecanismo principal de adrizado | respaldo, y para la condicion quilla-arriba en playa |

## 2. Pesos

| Item | Baseline | Variante |
|---|---|---|
| Quilla (plomo, remanente del tope 750) | 213.0 kg | **210.5 kg** (paga el flotador) |
| Flotador de tope (z = 9.55 m) | — | +2.5 kg |
| Desplazamiento rosca | 750 kg | 750 kg (sin cambio) |
| VCG rosca | 0.256 m | 0.287 m (+31 mm — **cargado en las curvas**) |

## 3. Resultado de estabilidad (rosca, cockpit inundado, tanques vacios)

| | Baseline | Variante |
|---|---|---|
| AVS | 110° | GZ sigue positivo mas alla de 110° (salto a GZ ≈ 1.0 m al sumergirse el aparejo, ~93°) |
| Limite de recuperacion autonoma | 110° | **156°** |
| Equilibrio invertido | estable — queda tortuga | bolsillo residual 156–180°, 8× mas superficial |
| Energia que sostiene la tortuga | 2516 J | **302 J**, detras de una barrera de 2633 J |
| Veredicto operativo | NO auto-adrizante | **anti-tortuga + retorno autonomo hasta 156°** |

La afirmacion NO es "auto-adrizante desde 180.0° matematicos" (eso solo lo
cumple la variante angosta de 1.80 m, que rompe el brief). Es el barco del
brief con el vuelco resuelto y los numeros a la vista.

## 4. Condicion de diseno y operacion (nuevo)

- **Placa nueva junto a la caja de quilla**: AUTO-ADRIZANTE SOLO CON QUILLA
  ABAJO Y TRABADA · TANQUES VACIOS. QUILLA ARRIBA = SOLO BOTADURA / PLAYA.
- El **lastre de agua queda reclasificado**: de sistema mixto a sistema de
  rendimiento puro (tanque de barlovento con poca tripulacion). La curva
  auto-adrizante se calcula con tanques vacios: la seguridad nunca depende de
  llenarlos.
- Angulo de inundacion (37° a plena carga) y regla operativa del lastre (L7):
  sin cambios.

## 5. Modelo de calculo (nuevo modulo)

`calc/autoadrizante.py`: el aparejo sellado entra a la hidrostatica como
elementos de volumen a lo largo del palo + flotador; la flotacion se
re-resuelve por angulo (el casco flota mas alto con el aparejo sumergido).
Corrige la afirmacion de `docs/03` de que "el flotador no aparece en una
curva GZ". Mismo tratamiento del cockpit inundado que el base, con la misma
advertencia (no agrega el peso del agua atrapada: optimista).

## 6. Costos

Delta de la variante: **USD 240–760** (~0.5 % del costo medio USD 64,400).
Detalle en `costs.txt`.

## 7. Lo que NO cambia

Casco (2.35 m, formas, offsets identicos), cockpit 6 plazas, piso
autoachicable (+56 mm a plena carga), bancos-tanque 2×244 L, cuddy y
tambuchos, quilla pivotante 1.29 m, timon unico abatible, aparejo 22 m² sin
winches, motor electrico + bateria bajo el piso, estructura HDPE doble piel,
sobre dimensional (0 violaciones), remolque < 750 kg sin frenos.

## 8. Equivalencia de salidas (out/ → autoadrizante/)

| out/ (baseline) | autoadrizante/ (variante) | Cambio |
|---|---|---|
| report.txt | report.txt | reporte de la variante: pesos con flotador, curvas, dimensionado, condiciones |
| gz_curves.png | gz_curves.png | curvas con y sin paquete de tope |
| hull_lines.png | hull_lines.png | identico en formas (casco sin cambios) |
| hull/offsets/boat baseline | hull/offsets/boat autoadrizante | 3DM agrega capa `flotador-tope` |
| planos.pdf (7 laminas) | planos.pdf (**8 laminas**) | + L8: flotador, mastil sellado, placa |
| preview_3dm / preview_cockpit | idem | regenerados del 3DM de la variante |
| foto_patagonia / foto_aira | idem | encuadre mas alto: el flotador en cuadro |
| diseno_colores / diseno_perfil | idem | regenerados (estilo sin cambios) |
| selfrighting.gif + anim_*.png | idem | **nueva fisica**: soltados a 150°, con/sin paquete de tope (antes: base vs casco angosto 1.80 m) |
| audit.txt (15 checks) | audit.txt (**22 checks**) | + 7 verificaciones del paquete de tope |
| costs.txt | costs.txt | + delta de la variante |
| presentacion.pdf (12 pag.) | presentacion.pdf | presentacion propia de la variante |
| trade_study/options/trade_frontier | **opciones.txt / opciones.json / opciones_gz.png / opciones_board.png** | exploracion NUEVA sobre el espacio que abre el modelo con aparejo: 8 opciones (mastil sellado solo, flotador 60/80 L, bolsa inflable 150 L, tanques bajo el piso solos y combinados, casco angosto) medidas contra notes.txt; la comparacion, matriz y recomendacion van integradas en la **seccion 4 de presentacion.pdf** |

## Regeneracion

```bash
python3 -m calc.autoadrizante             # fisica: report, gz_curves, specs
python3 -m geom.autoadrizante             # stl, offsets, 3dm, planos, perfil
python3 -m geom.render_autoadrizante     # lines, previews, fotos, diseno
python3 -m geom.animate_autoadrizante    # gif + frames
python3 -m calc.audit_autoadrizante      # audit + costs
python3 -m calc.opciones_autoadrizante   # exploracion de opciones (txt/json/png)
python3 -m calc.presentacion_autoadrizante   # incluye la comparacion de opciones
```

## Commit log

2026-08-07 Velero abierto HDPE 6.48 m: modelo parametrico, variante auto-adrizante y visor web
    [boat_autoadrizante.3dm, boat_baseline.3dm, boat_selfrighting.3dm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]
2026-08-07 Layered 3D viewer + realistic bench-tank geometry
    - geom/export_web.py: layered boat -> boat_web.json for the web viewer
    - index.html: per-layer toggle chips (casco, bancos, quilla, timon, aparejo,
    velas, flotador, flotaciones, secciones) over the full 3DM content
    - export_3dm.bench_mesh: benches lofted station-by-station inside the hull
    (8 mm off the cockpit wall, capped under the local deck edge) instead of
    constant boxes that pierced the aft deck and z-fought the walls
    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
    [boat_autoadrizante.3dm, boat_baseline.3dm, boat_selfrighting.3dm]
2026-08-07 3D motion in the web viewer: physics-driven capsize/righting + sailing mode
    - geom/export_sim_web.py: roll trajectories (with/without masthead package)
    and per-heel waterline table -> righting_sim.json (4 kB)
    - index.html: animation bar on the layered model — drop at 150° with float
    (returns upright), without float (turtles), gentle sailing motion, stop;
    boat rolls about the simulation's body axis with the solved waterline
    applied per frame, HUD shows heel and time
2026-08-07 Concurso UTN: competencia de diseño naval con IA sobre el proyecto
    - concurso/bases.md + desafios.md: reglas, puntaje (100 auto + 40 jurado),
    rol del Líder de IA (director humano + copiloto agente), cronograma
    - concurso/plantilla_diseno.json: entrega de 14 parámetros con rangos
    - concurso/evaluar.py: evaluador oficial sobre la cadena de cálculo real
    (GZ 0-180 inundado, pesos con plomo-remanente, sobre dimensional) ~10 s
    - concurso/leaderboard.py + leaderboard.json + página del concurso
    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
